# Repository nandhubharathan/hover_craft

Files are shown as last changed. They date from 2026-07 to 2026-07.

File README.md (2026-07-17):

# 🚁 Autonomous AI Hovercraft — v5.5

> **Self-correcting autonomous hovercraft** — if someone pushes it, tilts it, or the wind moves it off course, the craft detects the drift and steers itself back to its locked heading automatically. No input from the remote required.

**Platform:** Raspberry Pi Pico (RP2040) · MicroPython  
**Chassis:** 22 cm × 14.5 cm · ~400 g  
**Motors:** 2× Emax 1700KV BLDC · 9.2 cm 2-Blade Props  
**Servo:** MG90S (thrust vectoring / rudder)  
**Battery:** 11.1V 3S 80C LiPo  
**Modes:** Manual RC + Autonomous AI Stabilization

---

## 📁 Project Structure

```
hover_craft/
│
├── firmware/                        # All source code
│   ├── pico/                        # Raspberry Pi Pico (MicroPython)
│   │   ├── main.py                  # Dual-core entry point
│   │   ├── hover_control.py         # PWM, heading memory, safety
│   │   ├── mlp_logic.py             # TinyML inference engine (100 Hz)
│   │   └── weights.py               # MLP weights (int8 quantized)
│   │
│   ├── transmitter_nano/            # Arduino Nano — Hand Controller TX
│   │   └── transmitter_nano.ino     # 433 MHz TX, 6-byte packet
│   │
│   ├── receiver_nano/               # Arduino Nano — RX UART Bridge
│   │   └── receiver_nano.ino        # 433 MHz RX → Pico UART bridge
│   │
│   └── esp32_vision/                # ESP32-CAM — Vision + Ultrasonic
│       └── sketch_apr6a/
│           └── sketch_apr6a.ino     # Geometry + HC-SR04 streamer
│
├── 3d_designs/                      # 3D printable STL files (full chassis)
│   ├── 1-upper-hull-main-body.stl   # Main upper hull body
│   ├── 2-lower-hull.stl             # Lower hull base plate
│   ├── 3-thrust-motor-mount.stl     # Thrust BLDC motor bracket
│   ├── 4-roll-hoop.stl              # Roll protection hoop
│   ├── 5-lower-skirt-mount.stl      # Lower skirt attachment ring
│   ├── 6-upper-skirt-mount-complete.stl  # Upper skirt clamp assembly
│   ├── propeller.stl                # Prop guard / duct
│   ├── camerabox.stl                # ESP32-CAM enclosure
│   ├── joystick.stl                 # Handheld controller shell
│   └── joycover.stl                 # Controller top cover
│
├── simulation/                      # ROS2 / Gazebo SITL
│   ├── hovercraft.urdf              # Robot description
│   ├── hover_sim.launch.py          # ROS2 launch file
│   ├── sitl_bridge.py               # Software-in-the-loop bridge
│   └── world/
│       └── hover_lab.world          # Gazebo world
│
├── circuit_diagrams.md              # Full wiring diagrams (Mermaid)
├── Connection_Map.txt               # Pin-by-pin connection map
├── README.md                        # This file
└── .gitignore
```

---

## 🏗️ System Architecture

```
🎮 Hand Controller          📻 RF Link         🚁 Hovercraft
─────────────────           ──────────         ─────────────

TX Arduino Nano             433 MHz            RX Arduino Nano
  Joystick (A0/A1)   ─────►  ASK  ──────►     (UART Bridge)
  AI Switch  (D2)           2000bps              D12 ← RF DATA
  Lift Button (D3)                               D11 → Pico GP9
  D12 → RF TX DATA                           (1kΩ/2kΩ divider)
                                                      │
                                                      ▼
                                           Raspberry Pi Pico
                                           ┌──────────────────────────┐
                                           │ Core 0 (I/O)             │
                                           │  UART1 GP9 ← Nano Bridge │
                                           │  UART0 GP1 ← ESP32-Cam   │
                                           │  Shared State (mutex)    │
                                           │                          │
                                           │ Core 1 (Control 100Hz)   │
                                           │  MPU-6050 I2C (GP4/GP5)  │
                                           │  MLP TinyML Inference    │
                                           │  Heading Memory + PI     │
                                           │  hover_control PWM       │
                                           │       ↓      ↓      ↓   │
                                           │  GP16    GP17    GP18    │
                                           └───┼───────┼────────┼────┘
                                            Lift ESC Thrust  Rudder
                                            BLDC    ESC BLDC  Servo
```

### ESP32-CAM Sensor Node

```
ESP32-CAM ──── HC-SR04 Ultrasonic (GPIO 13 TRIG / GPIO 15 ECHO)
     │
     └── GPIO1 TX ──► Pico GP1 (UART0, 115200 bps)
         4-byte packet: [0xD4][aspect×10][bb_height][ultra_dist_cm]
```

---

## 🔌 Hardware Requirements

### On-Board (Hovercraft)

| Component | Qty | Notes |
|---|-----|---|
| Raspberry Pi Pico (RP2040) | 1 | Flight controller |
| Arduino Nano (ATmega328P) | 1 | RX UART Bridge |
| 433 MHz RX Module | 1 | ASK/OOK receiver |
| ESP32-CAM (AI-Thinker) | 1 | Vision + ultrasonic |
| HC-SR04 Ultrasonic | 1 | Proximity sensing |
| MPU-6050 IMU | 1 | Gyro + accelerometer |
| Emax 1700KV BLDC | 2 | Lift + Thrust motors |
| 30A ESC | 2 | Lift + Thrust ESCs |
| MG90S Servo | 1 | Rudder / thrust vector |
| 9.2 cm 2-Blade Prop | 2 | CW + CCW pair |
| 11.1V 3S 80C LiPo | 1 | Main power |
| 5V BEC | 1 | Regulated supply |
| 1kΩ / 2kΩ Resistors | 2 | 5V→3.3V level shifter |
| 4.7kΩ Resistors | 2 | I2C SDA/SCL pull-ups |
| ball bearing 6702 | 1 |15x21x4mm|

### Hand Controller (Transmitter)

| Component | Qty | Notes |
|---|-----|---|
| Arduino Nano (ATmega328P) | 1 | TX controller |
| 433 MHz TX Module | 1 | ASK/OOK transmitter |
| Dual-axis Joystick | 1 | Thrust + steer |
| Toggle Switch | 1 | AI mode enable |
| Momentary Push Button | 1 | Lift toggle |
| 9V Battery | 1 | Controller power |

---

## 📡 Wiring Summary

### RF Signal Chain

```
TX Nano D12 ──[433MHz RF]──► RX Nano D12
                                  │
                              RX Nano D11 (5V SoftwareSerial @ 57600bps)
                                  │
                            [1kΩ]─┬─── Pico GP9 (UART1 RX, 3.3V)
                                  │
                                [2kΩ]
                                  │
                                 GND
```

> ⚠️ **Critical:** The Nano outputs 5V on D11. The Pico GPIO is 3.3V max. The 1kΩ/2kΩ resistor divider is **mandatory** to avoid damaging the Pico.

### Pico Pin Map

| GPIO | Function | Protocol |
|---|---|---|
| GP0 | ESP32-Cam RX (Pico TX, reserved) | UART0 115200 |
| GP1 | ESP32-Cam TX → Pico RX | UART0 115200 |
| GP4 | MPU-6050 SDA | I2C0 400 kHz |
| GP5 | MPU-6050 SCL | I2C0 400 kHz |
| GP8 | Nano Bridge TX (reserved) | UART1 57600 |
| GP9 | Nano Bridge D11 → Pico RX | UART1 57600 |
| GP16 | Lift BLDC ESC | PWM 50 Hz |
| GP17 | Thrust BLDC ESC | PWM 50 Hz |
| GP18 | MG90S Rudder Servo | PWM 50 Hz |

### RX Nano (Bridge) Pin Map

| Pin | Function |
|-----|---|
| D12 | 433 MHz RX module DATA (RadioHead rxPin) |
| D11 | SoftwareSerial TX → Pico GP9 (via divider) |
| D10 | RadioHead PTT (unused, held HIGH) |
| 5V | Power from BEC |
| GND | Common ground with Pico |

---

## 📦 UART Packet Format

### RF Packet: TX Nano → RX Nano (6 bytes, RadioHead RH_ASK @ 2000bps)

| Byte | Field | Type | Range |
|---|---|---|---|
| 0 | thrust | uint8 | 0–255 |
| 1 | steer | int8 | -100…+100 |
| 2 | liftToggle | uint8 | 0 or 1 |
| 3 | aiMode | uint8 | 0 or 1 |
| 4 | brakeMode | uint8 | 0 or 1 |
| 5 | checksum | uint8 | XOR of bytes 0–4 |

### UART Frame: RX Nano → Pico GP9 (8 bytes, 57600 bps 8N1)

```
[0xAA][0x55][thrust][steer][lift][ai][brake][checksum]
 sync0  sync1   1B     1B    1B   1B    1B      1B
```

Pico unpack: `struct.unpack('<BbBBBB', frame[2:])` 

---

## 🧠 MLP Neural Network

**Architecture:** 7 inputs → 8 hidden (tanh) → 4 outputs (sigmoid)

| Layer | Nodes | Activation |
|---|---|---|
| Input | 7 | — |
| Hidden | 8 | tanh (256-entry LUT) |
| Output | 4 | sigmoid (via tanh identity) |

**Inputs:** `[ax, ay, az, joy_x, joy_y, obstacle_flag, yaw_rate]`  
**Outputs:** `[lift_trim_µs, thrust_trim_µs, servo_trim_µs, alert/confidence]`

**TinyML Optimizations:**
- `int8` quantized weights (range -127..127), dequantized × (1/127)
- 256-entry LUT tanh/sigmoid — ~8× faster than `math.tanh` on M0+
- Pre-allocated buffers — zero GC pressure at 100 Hz
- Confidence gate: if `alert < 0.3` → all trims zeroed

**Target:** < 10 ms per inference on RP2040 @ 125 MHz

---

## ⚙️ PWM Reference (1700KV @ 12.6V)

| PWM | RPM | Purpose |
|-----|-----|---|
| 1000 µs | 0 | ESC armed / motor off |
| 1100 µs | ~2,142 | Thrust idle / dip manoeuvre |
| 1350 µs | ~7,497 | **Lift hover target** |
| 1500 µs | ~10,710 | Servo neutral |
| 1900 µs | ~19,278 | Thrust maximum |

---

## 🚀 Quick Start

### 1. Flash the Pico

```bash
cd firmware/pico
mpremote cp main.py hover_control.py mlp_logic.py weights.py :
```

### 2. Flash TX Arduino Nano

Open `firmware/transmitter_nano/transmitter_nano.ino` in Arduino IDE → select **Arduino Nano** → Upload.

### 3. Flash RX Arduino Nano (Bridge)

Open `firmware/receiver_nano/receiver_nano.ino` in Arduino IDE → select **Arduino Nano** → Upload.  
Verify Serial Monitor shows: `[OK] RadioHead ready on D12`

### 4. Flash ESP32-CAM

Open `firmware/esp32_vision/sketch_apr6a/sketch_apr6a.ino` in Arduino IDE → select **AI Thinker ESP32-CAM** → Upload.

### 5. Bench Test (NO PROPELLERS)

Pico Serial (Thonny) should show:
```
[CORE 0] I/O thread live — CAM UART0 | Nano UART1 @ 57600 baud
[CORE 1] ESCs armed — 100 Hz
[TX→PICO] THR=0 STR=0 LIFT=0 AI=0 BRK=0
```

### 6. Verify PWM Signals

| Channel | Idle | Active |
|---|---|---|
| GP16 (Lift) | 1000 µs | 1350 µs |
| GP17 (Thrust) | 1000 µs | scales with joystick |
| GP18 (Servo) | 1500 µs | ±500 µs with steer |

---

## 🛡️ Safety Checklist

- [ ] Replace placeholder `weights.py` with trained MLP weights before flight
- [ ] Confirm 6-byte TX packet matches `<BbBBBB>` Pico struct format
- [ ] Bench test without propellers — verify all PWM signals
- [ ] Test thrust-dip: observe 100 ms power dip during 180° servo flip
- [ ] Test failsafe: disconnect TX, confirm e-stop within 500 ms
- [ ] Verify voltage divider on Nano D11 → Pico GP9 before powering
- [ ] Add hardware kill switch between LiPo and ESCs
- [ ] Confirm all GNDs are tied: Nano RX ↔ Pico ↔ ESCs ↔ BEC

---

## 🔬 AI Autonomous Mode

When **AI Mode** is toggled ON (D2 switch on transmitter), the craft becomes self-correcting:

### 🔄 Self-Correction — The Key Feature

> **If the craft is pushed, bumped, tilted, or drifts off course by wind or surface irregularity — it corrects itself back to its original heading without any input from the remote.**

This works through a two-layer system running at 100Hz:

- **Heading Memory (Angle Integration):** The gyroscope's yaw rate is continuously integrated into a heading error value (in degrees). If the craft rotates away from its locked heading — whether from a bump, wind, or uneven surface — the error accumulates. Once it crosses 20°, the rudder servo fires a fixed 250 µs correction force to push it back.
- **Zero-Crossing Disengage:** When the craft returns to its locked heading, the correction immediately disengages and a 300 ms cooldown prevents the return momentum from triggering an over-correction in the opposite direction.
- **Tilt Correction (MLP):** The TinyML neural network reads the accelerometer and fires servo trim corrections (up to ±312 µs) to counteract roll tilt in real time.
- **Pilot Overrule:** If you move the joystick, heading memory clears instantly. On release, the craft re-locks to its new position as the fresh zero.

### Full Feature List

1. **Autonomous Heading Hold** — Locks heading at AI-on moment; corrects any external disturbance back to it
2. **Tilt-Rudder Correction** — MLP roll compensation via servo trim at 100 Hz
3. **Human Detection** — ESP32-CAM bounding box geometry → `STATE_BRAKING` (latched, joystick reset to exit)
4. **Ultrasonic Proximity Stop** — Fused with camera: forward thrust blocked within 22 cm, steering preserved for evasion
5. **Torque Offset Compensation** — Proportional rudder bias cancels lift motor rotational torque
6. **Gyro Debounce (Sustained-Spin Gate)** — 5 consecutive ticks above deadband required before integrating — filters vibration spikes
7. **AI Packet Debounce** — 5 consecutive `ai_mode=True` RF packets required before AI activates — prevents corrupt-packet false triggers
8. **Pilot Overrule + Heading Re-lock** — Pilot steering clears heading memory; heading re-locks on stick release

---

---

## 🖨️ 3D Design Files

All structural parts are fully 3D printable. Files are in the `3d_designs/` folder (STL format, ready to slice).

| File | Part | Notes |
|---|---|---|
| `1-upper-hull-main-body.stl` | Upper hull | Main body — houses Pico, Nano, IMU |
| `2-lower-hull.stl` | Lower hull | Base plate — mounts ESCs and LiPo |
| `3-thrust-motor-mount.stl` | Thrust motor bracket | Rear BLDC mount with servo clearance |
| `4-roll-hoop.stl` | Roll hoop | Protects electronics on tip-over |
| `5-lower-skirt-mount.stl` | Lower skirt ring | Clamps garbage-bag skirt to hull base |
| `6-upper-skirt-mount-complete.stl` | Upper skirt clamp | Seals skirt top to hull |
| `propeller.stl` | Prop guard / duct | Optional duct for efficiency |
| `camerabox.stl` | ESP32-CAM enclosure | Front-facing camera housing |
| `joystick.stl` | Controller shell | Handheld TX enclosure body |
| `joycover.stl` | Controller cover | TX enclosure top cap |

**Recommended print settings:** PLA/PETG · 20% infill · 0.2 mm layer height · 3 perimeters

---

## 🌐 Simulation (ROS2 / Gazebo)

```bash
# Launch Gazebo simulation
ros2 launch simulation/hover_sim.launch.py

# Run SITL bridge (connects Pico serial to ROS2)
python3 simulation/sitl_bridge.py
```

---

## 📋 Libraries Required

### Arduino (Nano TX + RX)
- [RadioHead](http://www.airspayce.com/mikem/arduino/RadioHead/) — `RH_ASK` driver
- `SPI.h` — bundled with Arduino IDE
- `SoftwareSerial.h` — bundled with Arduino IDE (RX Nano only)

### ESP32-CAM
- `esp_camera.h` — bundled with ESP32 Arduino core

### Pico (MicroPython)
- `machine`, `_thread`, `struct`, `time` — all built-in to MicroPython

---

## ⚠️ Known Notes

- **Baud rate:** `receiver_nano.ino` SoftwareSerial runs at **57600 bps**. Ensure `main.py` `UART(1, baudrate=57600)` matches.
- **SD card conflict:** ESP32-CAM GPIO 13/15 are shared with the SD card slot. Do **not** initialize the SD card.
- **Prop direction:** Lift prop pushes air DOWN (into skirt). Thrust prop pushes air AFT through rudder channel.
- **Weights:** `weights.py` ships with Xavier-initialized placeholder values. **Replace with trained weights before any flight.**
- **3.3V rule:** MPU-6050 must be powered from Pico 3V3 pin only.

---

*Karunya Institute of Technology and Sciences — B.Tech Project*

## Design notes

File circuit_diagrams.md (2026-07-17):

# Hovercraft v5.5 — Circuit Diagrams

## 1. Hovercraft (On-Board Electronics)

### System Overview

```mermaid
graph TB
    subgraph POWER["🔋 Power"]
        BATT["LiPo Battery<br/>11.1V 3S"]
        BEC["BEC 5V"]
    end

    subgraph BRAIN["🧠 Flight Controller"]
        PICO["Raspberry Pi Pico<br/>(RP2040)"]
    end

    subgraph SENSORS["📡 Sensors"]
        IMU["MPU-6050<br/>Gyro + Accel"]
        ESP["ESP32-CAM<br/>AI-Thinker"]
        ULTRA["HC-SR04<br/>Ultrasonic"]
    end

    subgraph ACTUATORS["⚙️ Actuators"]
        LIFT_ESC["Lift ESC"]
        LIFT_MOTOR["Lift BLDC<br/>1700KV"]
        THRUST_ESC["Thrust ESC"]
        THRUST_MOTOR["Thrust BLDC<br/>1700KV"]
        SERVO["Rudder Servo<br/>MG90S"]
    end

    subgraph RF["📻 RF Receive Chain"]
        RX433["433 MHz RX<br/>Module"]
        NANO_RX["Arduino Nano<br/>(RX UART Bridge)"]
    end

    BATT --> BEC
    BATT --> LIFT_ESC
    BATT --> THRUST_ESC
    BEC --> PICO
    BEC --> ESP
    BEC --> SERVO
    BEC --> NANO_RX

    PICO -->|"GP16 PWM 50Hz"| LIFT_ESC --> LIFT_MOTOR
    PICO -->|"GP17 PWM 50Hz"| THRUST_ESC --> THRUST_MOTOR
    PICO -->|"GP18 PWM 50Hz"| SERVO

    IMU -->|"I2C (GP4/GP5) 400kHz"| PICO
    PICO -->|"3V3"| IMU
    ESP -->|"UART0 GP1 115200bps"| PICO
    ULTRA -->|"TRIG GPIO13"| ESP
    ESP -->|"ECHO GPIO15 (via divider)"| ULTRA

    RX433 -->|"DATA → D12"| NANO_RX
    NANO_RX -->|"D11 → 1kΩ/2kΩ → GP9<br/>SoftSerial 57600bps"| PICO
    BEC -->|"5V"| RX433
```

---

### Complete Signal Chain (RF → Control)

```mermaid
graph LR
    subgraph TX["🎮 Transmitter (Hand Controller)"]
        JOY["Joystick<br/>A0/A1"]
        SW["Switches<br/>D2 D3"]
        TX_NANO["TX Nano<br/>(ATmega328P)"]
        RF_TX["433MHz TX<br/>ASK Module"]
    end

    subgraph AIR["🌊 RF Link"]
        LINK["433 MHz OOK<br/>2000 bps"]
    end

    subgraph CRAFT["🚁 Hovercraft"]
        RF_RX["433MHz RX<br/>Module"]
        RX_NANO["RX Nano<br/>(UART Bridge)"]
        DIV["1kΩ/2kΩ<br/>Divider"]
        PICO2["Pico GP9<br/>UART1 RX"]
    end

    JOY --> TX_NANO
    SW --> TX_NANO
    TX_NANO -->|"D12 RadioHead"| RF_TX
    RF_TX --> LINK --> RF_RX
    RF_RX -->|"DATA → D12"| RX_NANO
    RX_NANO -->|"D11 SoftSerial<br/>57600bps"| DIV
    DIV -->|"3.3V safe"| PICO2
```

---

### Pico (RP2040) Pin Map

```mermaid
graph LR
    subgraph PICO["Raspberry Pi Pico (RP2040)"]
        direction TB
        GP0["GP0 — UART0 TX (reserved)"]
        GP1["GP1 — UART0 RX ← ESP32-Cam"]
        GP4["GP4 — I2C0 SDA"]
        GP5["GP5 — I2C0 SCL"]
        GP8["GP8 — UART1 TX (reserved)"]
        GP9["GP9 — UART1 RX ← Nano RX Bridge"]
        GP16["GP16 — Lift ESC PWM"]
        GP17["GP17 — Thrust ESC PWM"]
        GP18["GP18 — Servo PWM"]
        V3["3V3 OUT → MPU-6050"]
        GND["GND — Common"]
    end

    ESP32["ESP32-CAM GPIO1 TX"] -->|"115200 baud"| GP1
    MPU_SDA["MPU-6050 SDA"] <-->|"I2C 400kHz"| GP4
    MPU_SCL["MPU-6050 SCL"] <-->|"I2C 400kHz"| GP5
    NANO_D11["Nano RX D11<br/>(via 1kΩ/2kΩ divider)"] -->|"57600 baud"| GP9
    GP16 -->|"50 Hz PWM"| LIFT["Lift ESC Signal"]
    GP17 -->|"50 Hz PWM"| THRUST["Thrust ESC Signal"]
    GP18 -->|"50 Hz PWM"| RUDDER["Rudder Servo Signal"]
```

---

### Arduino Nano RX Bridge — Pin Map

```mermaid
graph LR
    subgraph NANO_RX_BOARD["Arduino Nano (RX UART Bridge)"]
        direction TB
        ND12["D12 — RadioHead RX Data"]
        ND11["D11 — SoftwareSerial TX (to Pico)"]
        ND10["D10 — RadioHead PTT (unused, HIGH)"]
        N5V["5V — VCC from BEC"]
        NGND["GND — Common"]
    end

    RF433["433 MHz RX<br/>Module DATA"] -->|"OOK signal"| ND12
    ND11 -->|"5V 57600bps"| R1["1kΩ"]
    R1 --> PICO_GP9["Pico GP9 (UART1 RX)"]
    R1 --> R2["2kΩ"]
    R2 --> GND_NODE["GND"]
    N5V --- BEC_5V["BEC 5V"]
    NGND --- PICO_GND["Pico GND"]
```

---

### Detailed Wiring Table — Hovercraft

| Connection | From | Pin | To | Pin | Notes |
|---|---|-----|-----|-----|---|
| **Lift ESC** | Pico | GP16 | ESC Signal | White | 50 Hz PWM, 1000–1350 µs |
| **Thrust ESC** | Pico | GP17 | ESC Signal | White | 50 Hz PWM, 1000–1900 µs |
| **Rudder Servo** | Pico | GP18 | Servo Signal | Orange | 50 Hz PWM, 500–2500 µs |
| **IMU SDA** | Pico | GP4 | MPU-6050 | SDA | I2C0 @ 400 kHz, 3.3V |
| **IMU SCL** | Pico | GP5 | MPU-6050 | SCL | I2C0 @ 400 kHz, 3.3V |
| **IMU Power** | Pico | 3V3 | MPU-6050 | VCC | 3.3V only |
| **IMU Ground** | Pico | GND | MPU-6050 | GND | Common ground |
| **ESP32 → Pico** | ESP32 | GPIO1 (TX) | Pico | GP1 (RX) | UART0, 115200 baud |
| **Ultrasonic TRIG** | ESP32 | GPIO13 | HC-SR04 | TRIG | 3.3V output |
| **Ultrasonic ECHO** | ESP32 | GPIO15 | HC-SR04 | ECHO | ⚠️ 5V→3.3V divider needed |
| **433MHz RX → Nano** | 433MHz RX | DATA | Nano RX | D12 | RadioHead RH_ASK rxPin |
| **Nano RX → Divider** | Nano RX | D11 | Resistor | 1kΩ | SoftSerial TX 5V |
| **Divider → Pico** | Resistor | 2kΩ | Pico | GP9 (RX) | UART1, 57600 baud, 3.3V |
| **Nano RX Power** | BEC | 5V | Nano RX | VIN/5V | 5V supply |
| **Nano RX Ground** | Nano RX | GND | Pico | GND | MUST share common ground |

### Nano RX → Pico Voltage Divider (5V → 3.3V)

```
Nano RX D11 (5V) ──[1kΩ]──┬── Pico GP9 (UART1 RX, 3.3V)
                            │
                          [2kΩ]
                            │
                           GND
```

> [!IMPORTANT]
> The Arduino Nano outputs **5V** logic on D11. The Pico GPIO is **3.3V only** — connecting them directly **will damage the Pico**. The 1kΩ/2kΩ resistor divider brings 5V down to ~3.33V (safe). The SoftwareSerial runs at **57600 bps**; the Pico UART1 must also be configured at 57600 bps.

---

### ESP32-CAM Wiring

```mermaid
graph LR
    subgraph ESP["ESP32-CAM (AI-Thinker)"]
        GPIO1["GPIO 1 — Serial TX"]
        GPIO3["GPIO 3 — Serial RX (unused)"]
        GPIO13["GPIO 13 — HC-SR04 TRIG"]
        GPIO15["GPIO 15 — HC-SR04 ECHO"]
        ESP_5V["5V IN"]
        ESP_GND["GND"]
    end

    GPIO1 -->|"115200 baud"| PICO_RX["Pico GP1 (UART0 RX)"]
    GPIO13 -->|"10µs pulse"| TRIG["HC-SR04 TRIG"]
    ECHO_PIN["HC-SR04 ECHO"] -->|"via 5V→3.3V divider"| GPIO15
    ESP_5V --- BEC_5V["BEC 5V"]
    ESP_GND --- COMMON_GND["Common GND"]
```

> [!WARNING]
> GPIO 13 and 15 are shared with the SD card slot on the AI-Thinker ESP32-CAM. **Do NOT initialize the SD card** when using the ultrasonic sensor.

---

## 2. Remote Transmitter (Handheld Controller)

### Transmitter Overview

```mermaid
graph TB
    subgraph REMOTE["🎮 Remote Controller"]
        direction TB
        TX_NANO2["Arduino Nano<br/>(ATmega328P)"]
        JOY2["Dual-Axis<br/>Joystick"]
        AI_SW["AI Mode<br/>Toggle Switch"]
        LIFT_SW["Lift<br/>Push Button"]
        TX_MOD["433 MHz TX<br/>ASK Module"]
        BATT_TX["9V Battery"]
    end

    BATT_TX -->|"VIN"| TX_NANO2
    JOY2 -->|"A0 (Thrust)<br/>A1 (Steer)"| TX_NANO2
    AI_SW -->|"D2"| TX_NANO2
    LIFT_SW -->|"D3"| TX_NANO2
    TX_NANO2 -->|"D12 (Data)"| TX_MOD
    TX_NANO2 -->|"D10 (PTT)"| TX_MOD
```

---

### Transmitter Pin Map

```mermaid
graph LR
    subgraph NANO_TX["Arduino Nano (TX Controller)"]
        direction TB
        A0_TX["A0 — Thrust (Joystick X)"]
        A1_TX["A1 — Steer (Joystick Y)"]
        D2_TX["D2 — AI Mode Switch (PULLUP)"]
        D3_TX["D3 — Lift Button (PULLUP)"]
        D10_TX["D10 — PTT (RadioHead)"]
        D11_TX["D11 — RX (unused)"]
        D12_TX["D12 — TX Data (RadioHead)"]
        VIN_TX["VIN — 9V Battery"]
        V5_TX["5V OUT — TX Module VCC"]
        GND_TX["GND"]
    end

    JOY_X["Joystick X<br/>(Thrust/Brake)"] --> A0_TX
    JOY_Y["Joystick Y<br/>(Steer L/R)"] --> A1_TX
    AI_TOG["AI Toggle<br/>Switch"] --> D2_TX
    LIFT_BTN["Lift Button<br/>(Momentary)"] --> D3_TX
    D12_TX --> RF_TX2["433 MHz TX<br/>Data Pin"]
    D10_TX --> RF_PTT["433 MHz TX<br/>PTT Pin"]
    V5_TX --> RF_VCC["433 MHz TX<br/>VCC"]
```

---

### Detailed Wiring Table — Transmitter

| Connection | From | Pin | To | Pin | Notes |
|---|---|-----|-----|-----|---|
| **Joystick X** | Joystick | VRx | TX Nano | A0 | Thrust axis (fwd/back) |
| **Joystick Y** | Joystick | VRy | TX Nano | A1 | Steer axis (left/right) |
| **Joystick VCC** | TX Nano | 5V | Joystick | +5V | 5V reference |
| **Joystick GND** | TX Nano | GND | Joystick | GND | Common ground |
| **AI Toggle** | Switch | COM | TX Nano | D2 | `INPUT_PULLUP` — LOW = AI ON |
| **AI Toggle GND** | Switch | NC | TX Nano | GND | Switch to ground |
| **Lift Button** | Button | COM | TX Nano | D3 | `INPUT_PULLUP` — press to toggle |
| **Lift Button GND** | Button | NC | TX Nano | GND | Switch to ground |
| **433 TX Data** | TX Nano | D12 | TX Module | DATA | RadioHead RH_ASK @ 2000 bps |
| **433 TX PTT** | TX Nano | D10 | TX Module | PTT | Push-to-talk (RadioHead) |
| **433 TX VCC** | TX Nano | 5V | TX Module | VCC | 5V supply |
| **433 TX GND** | TX Nano | GND | TX Module | GND | Common ground |
| **433 TX Antenna** | — | — | TX Module | ANT | 17.3 cm wire (¼λ @ 433 MHz) |

---

### Joystick Axis Mapping

```
                   FORWARD (thrust > 0)
                        ↑
                   ┌────┼────┐
                   │    │    │
         LEFT ─────┼────●────┼───── RIGHT
        (steer-)   │    │    │   (steer+)
                   └────┼────┘
                        ↓
                   BACKWARD (BRK = 1)
```

| Joystick Position | Nano Value | Pico Variable | Effect |
|---|---|---|---|
| Forward | `rawX > 552` | `joy_y = 0.0–1.0` | Forward thrust |
| Backward | `rawX < 472` | `brake_mode = True` | Turn-around mode |
| Left | `rawY < 472` | `joy_x < 0` | Steer left |
| Right | `rawY > 552` | `joy_x > 0` | Steer right |
| Center | `472–552` | `joy_x/y ≈ 0` | Neutral (deadzone) |

---

### Serial Packet Format (TX Nano → 433MHz → RX Nano → Pico)

```
RF Packet (6 bytes, RadioHead RH_ASK):
┌────────┬───────┬──────┬───────┬──────────┬──────────┐
│ thrust │ steer │ lift │  AI   │  brake   │ checksum │
│ 0–255  │ ±100  │ 0/1  │  0/1  │   0/1    │   XOR    │
└────────┴───────┴──────┴───────┴──────────┴──────────┘
  1 B      1 B    1 B    1 B      1 B         1 B

UART Frame (8 bytes, RX Nano → Pico at 57600 bps):
┌──────┬──────┬────────┬───────┬──────┬───────┬──────────┬──────────┐
│ 0xAA │ 0x55 │ thrust │ steer │ lift │  AI   │  brake   │ checksum │
│ sync │ sync │ 0–255  │ ±100  │ 0/1  │  0/1  │   0/1    │   XOR    │
└──────┴──────┴────────┴───────┴──────┴───────┴──────────┴──────────┘
  1 B    1 B    1 B      1 B    1 B    1 B      1 B         1 B

Pico UART1: baudrate=57600, GP9 RX, 8N1
Pico struct.unpack: '<BbBBBB' (6 bytes after stripping 2 sync bytes)
```

---

## 3. Power Distribution

```mermaid
graph TD
    LIPO["LiPo 3S 11.1V"] --> LIFT_ESC2["Lift ESC<br/>(direct)"]
    LIPO --> THRUST_ESC2["Thrust ESC<br/>(direct)"]
    LIPO --> BEC2["BEC<br/>11.1V → 5V"]
    BEC2 --> PICO_5V["Pico VSYS (5V)"]
    BEC2 --> SERVO_V["Servo VCC (5V)"]
    BEC2 --> ESP_V["ESP32-CAM VCC (5V)"]
    BEC2 --> NANO_RX_V["Nano RX Bridge VIN (5V)"]
    BEC2 --> ULTRA_V["HC-SR04 VCC (5V)"]
    PICO_5V --> PICO_3V["Pico 3V3 OUT"]
    PICO_3V --> IMU_V["MPU-6050 VCC (3.3V)"]

    TX_BATT["9V Battery (TX)"] --> TX_NANO_V["TX Nano VIN"]
    TX_NANO_V --> TX_5V["TX Nano 5V"]
    TX_5V --> RF_TX_V["433MHz TX Module VCC"]
```

> [!TIP]
> Use a dedicated BEC (not the ESC's built-in BEC) for clean 5V. ESC BECs have switching noise that affects the MPU-6050 gyro readings.

---

## 4. MLP Neural Network Architecture

```
Input Layer (7 nodes)          Hidden Layer (8 nodes)      Output Layer (4 nodes)
─────────────────────          ──────────────────────      ─────────────────────
 ax  (accel X, g)    ──┐
 ay  (accel Y, g)    ──┤       ┌──────────────────┐        lift_trim_us  (±50 µs)
 az  (accel Z, g)    ──┼──────►│  8 × tanh nodes  ├───────►thrust_trim_us(±50 µs)
 joy_x (steer ±1)   ──┤       │  (LUT approx)    │        servo_trim_us (±312 µs)
 joy_y (thrust ±1)  ──┤       └──────────────────┘        alert / conf  (0–1)
 obstacle (0/1)      ──┤
 yaw_rate (°/s /250) ──┘

Weights: int8 quantized (-127..127), dequantized × (1/127)
Activations: 256-entry LUT tanh / sigmoid (no math.exp)
Inference: < 10 ms on RP2040 @ 125 MHz (100 Hz budget)
```

---

## 5. On-Board Dual-Core Architecture

```
┌──────────────────────────────────────────────────────────┐
│                    Raspberry Pi Pico (RP2040)            │
│                                                          │
│  ┌─ Core 0 (I/O) ─────────────────┐                     │
│  │  UART0 (GP1) ← ESP32-Cam       │                     │
│  │   Obstacle veto + Geometry 0xD4│                     │
│  │  UART1 (GP9) ← Nano RX Bridge  │                     │
│  │   57600bps framed packet parser │                     │
│  │            ↓                   │                     │
│  │   Shared State (thread-safe)   │                     │
│  │   joy_x/y, lift, ai, brake,    │                     │
│  │   obstacle_dir, cam_aspect,    │                     │
│  │   cam_height, ultra_dist       │                     │
│  └────────────────────────────────┘                     │
│                     ↓ _lock (mutex)                      │
│  ┌─ Core 1 (Control 100Hz) ───────────────────────┐     │
│  │  MPU-6050 I2C (GP4/GP5)                        │     │
│  │  MLP Inference (mlp_logic.py / weights.py)     │     │
│  │  hover_control.compute_targets()               │     │
│  │  Heading Memory + Pilot Overrule               │     │
│  │  Human Detection + Obstacle Veto               │     │
│  │            ↓                                   │     │
│  │   GP16 Lift ESC    GP17 Thrust ESC   GP18 Servo│     │
│  └────────────────────────────────────────────────┘     │
└──────────────────────────────────────────────────────────┘
```

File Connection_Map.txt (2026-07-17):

═══════════════════════════════════════════════════════════════
  HOVERCRAFT WIRING — CONNECTION MAP  (v5.5 — Nano RX Bridge)
  TX Nano ──433MHz──► RX Nano ──UART──► Raspberry Pi Pico
═══════════════════════════════════════════════════════════════

┌─────────────────────────────────────────────────────────────┐
│               TRANSMITTER (Arduino Nano — TX)               │
├──────────┬────────────┬─────────────────────────────────────┤
│ Pin      │ Type       │ Connection                          │
├──────────┼────────────┼─────────────────────────────────────┤
│ A0       │ Analog In  │ Joystick X-axis (Thrust)            │
│ A1       │ Analog In  │ Joystick Y-axis (Steering)          │
│ D2       │ Digital In │ AI Mode Toggle Switch (INPUT_PULLUP)│
│ D3       │ Digital In │ Lift Toggle Push Button (PULLUP)    │
│ D10      │ Digital Out│ 433 MHz TX PTT Pin (RadioHead)      │
│ D12      │ Digital Out│ 433 MHz TX Data Pin (RadioHead)     │
│ 5V       │ Power      │ Joystick VCC + TX Module VCC        │
│ GND      │ Power      │ Common Ground                       │
└──────────┴────────────┴─────────────────────────────────────┘

       ┌──────────433 MHz RF Link──────────┐
       │   TX Nano D12  ───►  RX Nano D12  │
       │   ASK @ 2000 bps (RadioHead)      │
       └───────────────────────────────────┘

┌─────────────────────────────────────────────────────────────┐
│           RECEIVER BRIDGE (Arduino Nano — RX)               │
│   Role: 433 MHz Wireless → Wired UART Bridge to Pico        │
├──────────┬────────────┬─────────────────────────────────────┤
│ Pin      │ Type       │ Connection                          │
├──────────┼────────────┼─────────────────────────────────────┤
│ D12      │ Digital In │ ← 433 MHz RX Module DATA pin        │
│ D10      │ Digital Out│ → 433 MHz RX PTT (unused, disabled) │
│ D11      │ SoftSerial │ → 1kΩ → Pico GP9  (UART1 RX)       │
│          │   TX       │   (+ 2kΩ to GND voltage divider)   │
│ 5V       │ Power      │ From BEC (or USB for bench testing) │
│ GND      │ Power      │ → Pico GND (common ground)         │
└──────────┴────────────┴─────────────────────────────────────┘

  Nano RX D11 ──[1kΩ]──┬── Pico GP9 (UART1 RX, 3.3V)
  (5V logic)            │
                       [2kΩ]
                        │
                       GND
  ⚠  MANDATORY: 5V Nano TX → 3.3V Pico RX level-shift!

  UART Protocol (Nano → Pico, 57600 bps, 8N1):
  [0xAA][0x55][thrust][steer][lift][ai][brake][checksum]
   sync0  sync1   1B     1B   1B   1B    1B      XOR

┌─────────────────────────────────────────────────────────────┐
│                 FLIGHT CONTROLLER (Raspberry Pi Pico)       │
├──────────┬────────────┬─────────────────────────────────────┤
│ Pin      │ Type       │ Connection                          │
├──────────┼────────────┼─────────────────────────────────────┤
│ GP0      │ UART0 TX   │ → ESP32-Cam GPIO3 RX (reserved)    │
│ GP1      │ UART0 RX   │ ← ESP32-Cam GPIO1 TX (115200 bps)  │
│ GP4      │ I2C0 SDA   │ ↔ MPU-6050 SDA (+ 4.7kΩ pull-up)  │
│ GP5      │ I2C0 SCL   │ ↔ MPU-6050 SCL (+ 4.7kΩ pull-up)  │
│ GP8      │ UART1 TX   │ → (reserved / unused)              │
│ GP9      │ UART1 RX   │ ← Nano RX D11 (via 1kΩ/2kΩ divider│
│          │            │   57600 bps SoftwareSerial)        │
│ GP16     │ PWM        │ → Lift BLDC ESC Signal              │
│ GP17     │ PWM        │ → Thrust BLDC ESC Signal            │
│ GP18     │ PWM        │ → MG90S Rudder Servo Signal         │
│ 3V3      │ Power      │ MPU-6050 VCC (3.3V ONLY!)           │
│ VSYS     │ Power      │ From BEC 5V (via LiPo regulator)    │
│ GND      │ Power      │ Common Ground                       │
└──────────┴────────────┴─────────────────────────────────────┘

═══════════════════════════════════════════════════════════════
  PACKET FORMAT (8 bytes total, Nano→Pico UART frame)
═══════════════════════════════════════════════════════════════

  Byte  Field       Type      Range     Notes
  ────  ─────────   ────────  ────────  ──────────────────────
  [0]   sync0       uint8     0xAA      Frame start marker
  [1]   sync1       uint8     0x55      Frame start marker
  [2]   thrust      uint8     0–255     Mapped to ESC 1000–2000µs
  [3]   steer       int8→u8   ±100      Pico re-interprets as int8
  [4]   liftToggle  uint8     0 or 1    Lift motor on/off state
  [5]   aiMode      uint8     0 or 1    Autonomous AI enable
  [6]   brakeMode   uint8     0 or 1    Joystick pulled back
  [7]   checksum    uint8     XOR       thrust^steer^lift^ai^brake

  Pico struct.unpack format: '<BbBBBB' (6 payload bytes after sync)

═══════════════════════════════════════════════════════════════
  SIGNAL CHAIN
═══════════════════════════════════════════════════════════════

  Joystick/Buttons
       │
       ▼
  TX Nano (ATmega328P)
  ├── Reads analog joystick (A0/A1), digital switches (D2/D3)
  ├── Builds 6-byte HoverPacket struct with XOR checksum
  └── Transmits via RadioHead RH_ASK @ 2000 bps on D12
       │
       ▼  [433 MHz OOK/ASK RF — one-way link]
       │
  RX Nano (ATmega328P)  ← NEW BRIDGE BOARD
  ├── RadioHead RH_ASK receives on D12
  ├── Validates checksum
  ├── Wraps in 8-byte framed packet [0xAA][0x55][...][csum]
  └── Forwards via SoftwareSerial on D11 @ 57600 bps
       │
       ▼  [Wired UART — 5V→3.3V voltage divider]
       │
  Raspberry Pi Pico (RP2040) — GP9 UART1 RX
  ├── Parses framed packet, validates sync + checksum
  ├── Core 0: I/O — feeds shared state (joy_x, joy_y, lift, ai, brake)
  └── Core 1: 100 Hz control loop → MLP → PWM → ESCs + Servo

═══════════════════════════════════════════════════════════════
  ESP32-CAM (AI-Thinker) — Obstacle + Geometry Sensor
═══════════════════════════════════════════════════════════════

  GPIO 1  → Pico GP1 (UART0 RX) @ 115200 bps
  GPIO 13 → HC-SR04 TRIG
  GPIO 15 ← HC-SR04 ECHO (via 5V→3.3V divider)
  5V IN   ← BEC 5V
  GND     → Common GND

  Packet: [0xD4][aspect_x10][bb_height][ultra_dist_cm]  4 bytes

═══════════════════════════════════════════════════════════════
  POWER WIRING
═══════════════════════════════════════════════════════════════

  3S LiPo (11.1 V)
    ├── ESC 1 (Lift BLDC)    → BEC 5V out
    ├── ESC 2 (Thrust BLDC)
    └── BEC 5V
          ├── Pico VSYS
          ├── Servo VCC
          ├── ESP32-Cam VCC
          ├── HC-SR04 VCC
          └── Nano RX VIN (or USB for bench)

  Pico 3V3 OUT → MPU-6050 VCC
  TX Nano      → Separate 9V battery or USB (hand controller)
  433 MHz TX   → TX Nano 5V pin
  433 MHz RX   → Nano RX 5V pin

═══════════════════════════════════════════════════════════════
  SAFETY NOTES
═══════════════════════════════════════════════════════════════

  ⚠  Nano RX D11 is 5V — MUST use 1kΩ/2kΩ divider to Pico GP9
  ⚠  433 MHz RX module VCC → Nano 5V (NOT Pico 3V3)
  ⚠  All GNDs connected: Nano RX GND ↔ Pico GND ↔ ESC GND
  ⚠  Remove propellers for ALL bench testing
  ⚠  Add hardware kill switch between LiPo and ESCs
  ⚠  MPU-6050 I2C needs 4.7kΩ pull-up resistors on SDA/SCL
  ⚠  Do NOT initialise SD card on ESP32-CAM (shares GPIO 13/15)

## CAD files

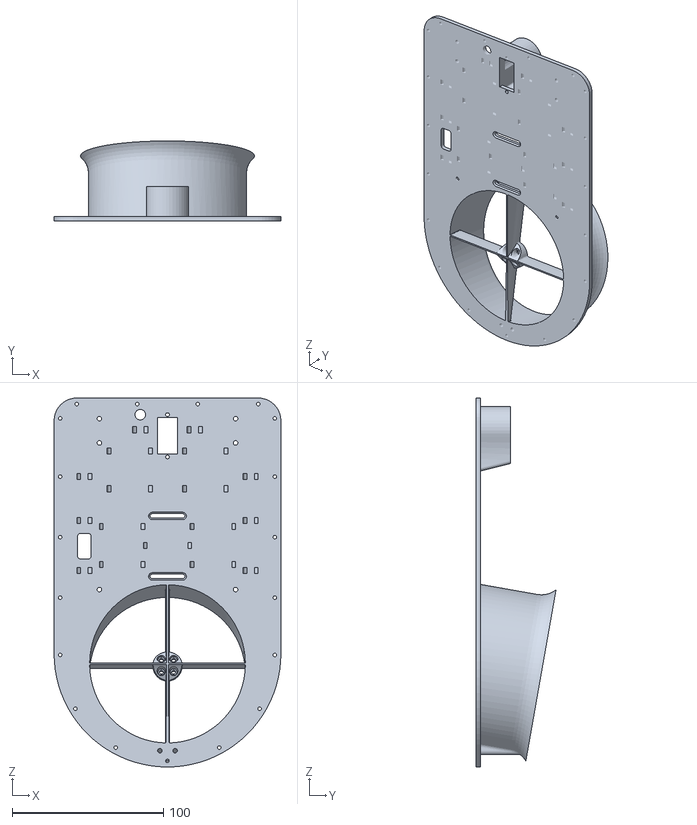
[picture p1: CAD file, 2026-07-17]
3d_designs/1-upper-hull-main-body.stl
150.0 x 53.0 x 244.0

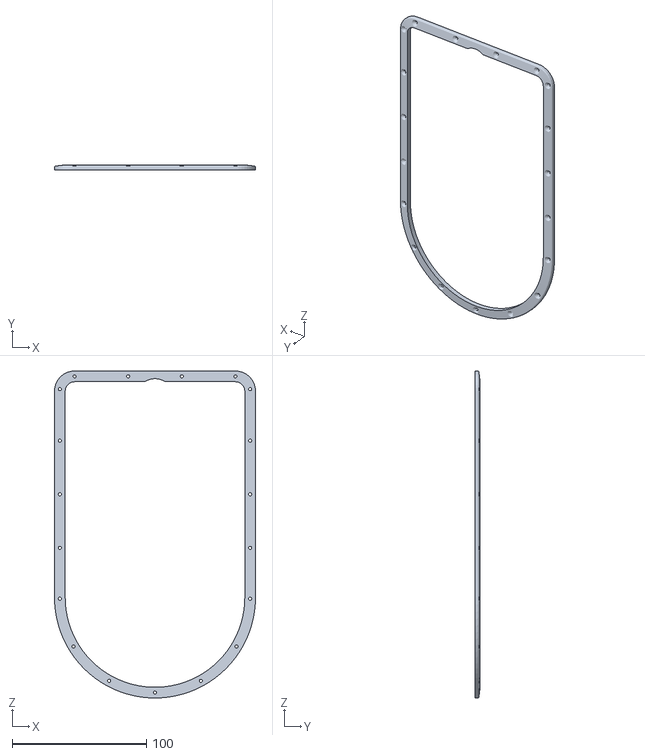
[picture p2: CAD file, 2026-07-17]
3d_designs/6-upper-skirt-mount-complete.stl
150.0 x 4.00 x 244.0

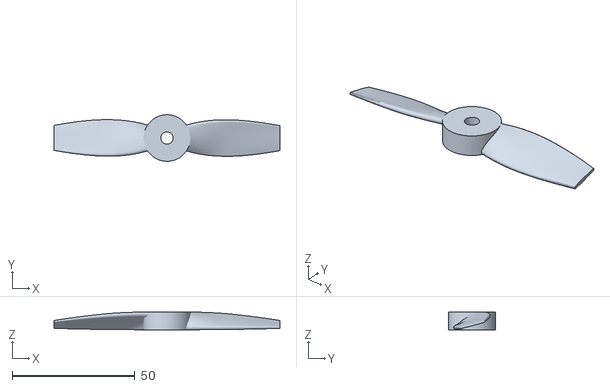
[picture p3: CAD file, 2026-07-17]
3d_designs/propeller.stl
92.0 x 19.0 x 7.29

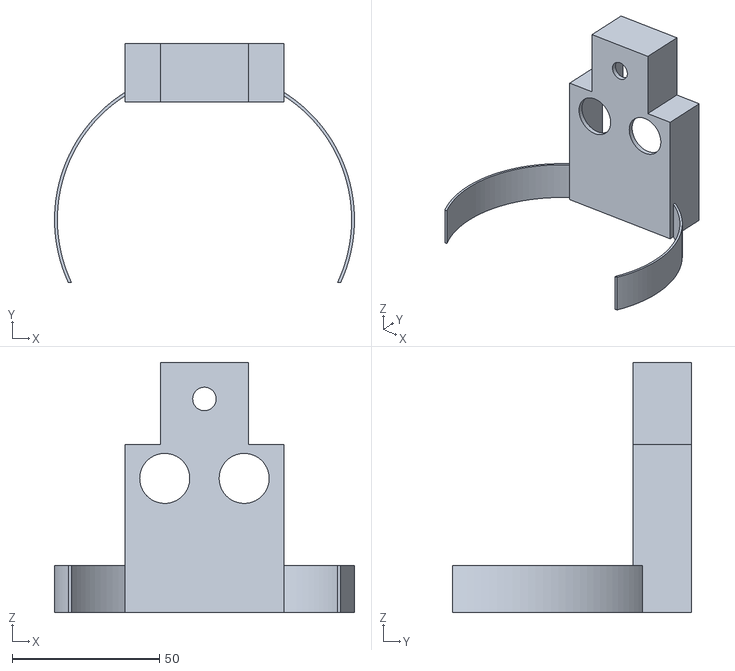
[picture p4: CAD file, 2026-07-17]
3d_designs/camerabox.stl
102.0 x 81.3 x 85.1

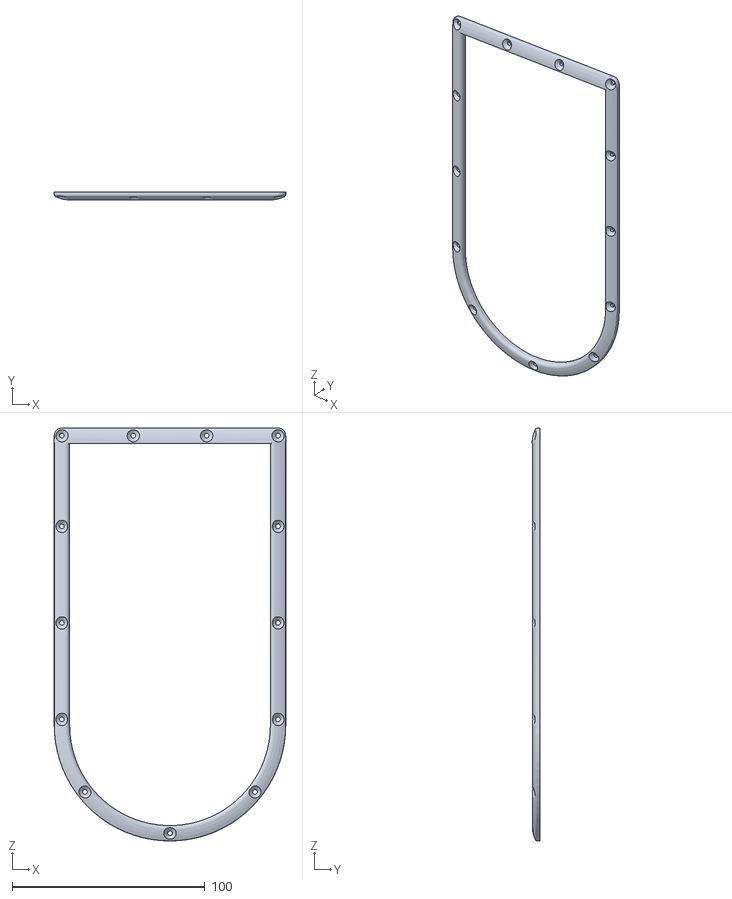
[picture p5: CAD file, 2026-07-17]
3d_designs/5-lower-skirt-mount.stl
120.0 x 4.00 x 214.0

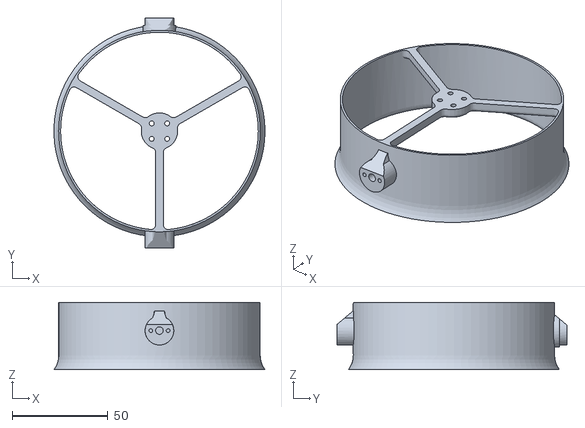
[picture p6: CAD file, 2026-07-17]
3d_designs/3-thrust-motor-mount.stl
110.0 x 120.0 x 35.0

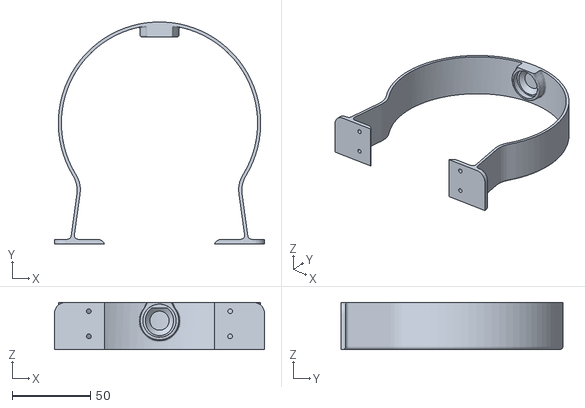
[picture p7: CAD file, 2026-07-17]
3d_designs/4-roll-hoop.stl
133.8 x 141.5 x 30.0

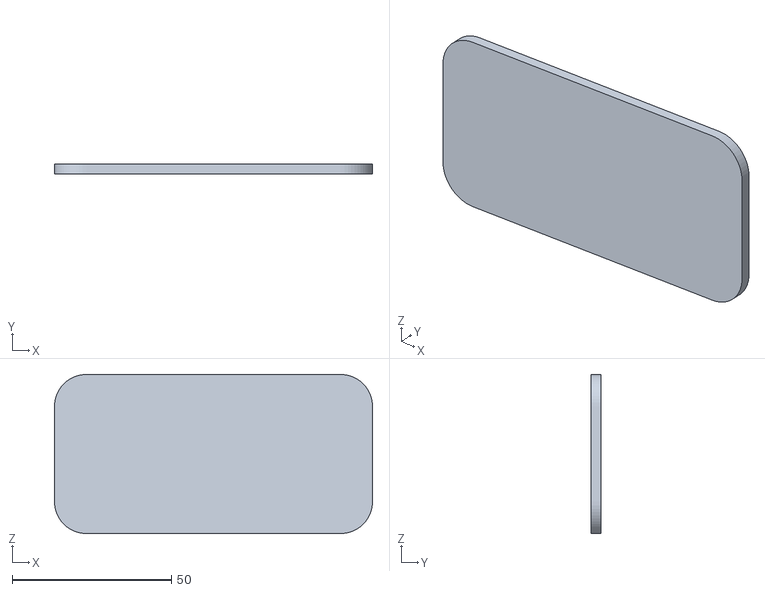
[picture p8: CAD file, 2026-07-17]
3d_designs/joycover.stl
100.0 x 3.00 x 50.0

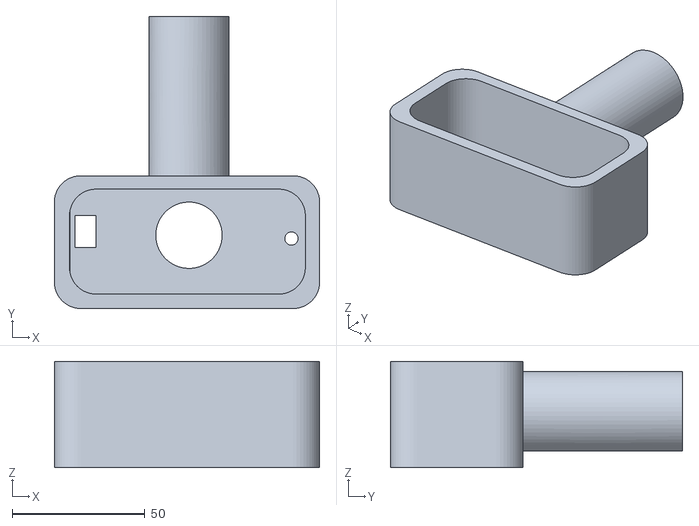
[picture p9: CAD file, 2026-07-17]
3d_designs/joystick.stl
100.0 x 110.0 x 40.0

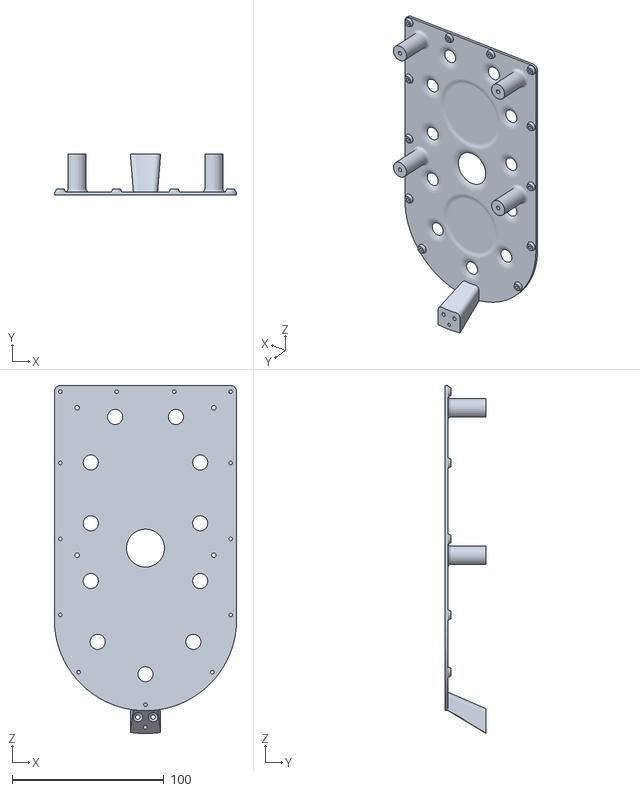
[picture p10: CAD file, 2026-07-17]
3d_designs/2-lower-hull.stl
120.0 x 27.0 x 229.0

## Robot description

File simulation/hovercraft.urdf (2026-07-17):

<?xml version="1.0" ?>
<robot name="hovercraft" xmlns:xacro="http://www.ros.org/wiki/xacro">

  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
  <link name="base_link">
    <inertial>
      <mass value="0.4"/>
      <origin xyz="0 0 0.02" rpy="0 0 0"/>
      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
    </inertial>

    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
  </link>

  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
  <link name="skirt_link">
    <inertial>
      <mass value="0.01"/>
      <origin xyz="0 0 -0.005" rpy="0 0 0"/>
      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
    </inertial>
    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
  </link>

  <joint name="skirt_joint" type="fixed">
    <parent link="base_link"/>
    <child link="skirt_link"/>
    <origin xyz="0 0 0" rpy="0 0 0"/>
  </joint>

  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
  <link name="thrust_mount">
    <inertial>
      <mass value="0.03"/>
      <origin xyz="-0.03 0 0.035" rpy="0 0 0"/>
      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
    </inertial>

    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
  </link>

  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
  <joint name="servo_joint" type="revolute">
    <parent link="base_link"/>
    <child link="thrust_mount"/>
    <origin xyz="-0.08 0 0.02" rpy="0 0 0"/>
    <axis xyz="0 0 1"/>
    <limit lower="0" upper="3.14159" effort="1.5" velocity="6.28"/>
    <dynamics damping="0.01" friction="0.005"/>
  </joint>

  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
  <link name="propeller_link">
    <inertial>
      <mass value="0.005"/>
      <origin xyz="0 0 0" rpy="0 0 0"/>
      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
    </inertial>

    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
  </link>

  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
  <joint name="prop_joint" type="continuous">
    <parent link="thrust_mount"/>
    <child link="propeller_link"/>
    <origin xyz="-0.03 0 0.06" rpy="0 0 0"/>
    <axis xyz="1 0 0"/>
    <dynamics damping="0.0001"/>
  </joint>

  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
  <link name="camera_link">
    <inertial>
      <mass value="0.01"/>
      <origin xyz="0 0 0" rpy="0 0 0"/>
      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
    </inertial>

    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
  </link>

  <joint name="camera_joint" type="fixed">
    <parent link="base_link"/>
    <child link="camera_link"/>
    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
    <origin xyz="0.10 0 0.035" rpy="0 0 0"/>
  </joint>

  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
  <link name="imu_link">
    <inertial>
      <mass value="0.002"/>
      <origin xyz="0 0 0" rpy="0 0 0"/>
      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
    </inertial>
  </link>

  <joint name="imu_joint" type="fixed">
    <parent link="base_link"/>
    <child link="imu_link"/>
    <origin xyz="0 0 0.02" rpy="0 0 0"/>
  </joint>

  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

</robot>

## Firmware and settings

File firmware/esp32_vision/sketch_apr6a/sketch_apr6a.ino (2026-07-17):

/*
 * sketch_apr6a.ino — ESP32-CAM Data Streamer (v5.4)
 * ====================================================
 * Platform  : ESP32-CAM (AI-Thinker)
 * Role      : Camera frame grab → person bounding-box geometry
 *             + HC-SR04 ultrasonic distance → 4-byte UART packet
 *
 * UART Protocol to Pico (115200 baud, 4 bytes):
 * ──────────────────────────────────────────────
 *   BYTE 0 : 0xD4         — sync header (geometry packet)
 *   BYTE 1 : aspect_x10   — uint8: bounding-box aspect ratio × 10
 *   BYTE 2 : bb_height    — uint8: bounding-box pixel height (0–255)
 *   BYTE 3 : ultra_dist   — uint8: ultrasonic distance in cm (0–255)
 *
 *   No CRC in this 4-byte compact format — sync header + field
 *   range validation on the Pico side provides adequate integrity.
 *
 * Ultrasonic Sensor (HC-SR04):
 *   TRIG_PIN = 13
 *   ECHO_PIN = 15
 *   Non-blocking timer: triggers pulse every 60 ms (well above the
 *   38 ms max echo timeout). Distance clamped to 255 cm on timeout.
 *
 * Camera:
 *   FRAMESIZE_QVGA (320×240) at ~10 FPS.
 *   Uses fb→buf for raw frame data.  Bounding-box detection is a
 *   placeholder — replace with your actual detection model or
 *   colour-blob / motion-delta logic.
 *
 * Pin Map (ESP32-CAM AI-Thinker):
 *   GPIO 13 → HC-SR04 TRIG
 *   GPIO 15 → HC-SR04 ECHO
 *   GPIO 1  → Serial TX (to Pico UART0 RX on GP1)
 *   GPIO 3  → Serial RX (unused by Pico)
 *
 * ⚠  GPIO 13 and 15 are shared with the SD card on AI-Thinker.
 *    SD card must NOT be initialised when using ultrasonic.
 */

#include "esp_camera.h"

// ── Ultrasonic Pins ──────────────────────────────────────────────────
#define TRIG_PIN  13
#define ECHO_PIN  15

// ── Non-blocking ultrasonic timing ───────────────────────────────────
//  State machine:
//    IDLE       → wait for interval timer
//    TRIGGERED  → 10µs pulse sent, waiting for echo
//
//  ULTRA_INTERVAL_MS must be > 38 ms (max echo round-trip for 6.5 m)
//  60 ms gives ~16 Hz measurement rate with zero camera interference.

#define ULTRA_INTERVAL_MS   60     // ms between trigger pulses
#define ULTRA_TIMEOUT_US    23200  // µs — max echo for ~400 cm (practical limit)

enum UltraState { ULTRA_IDLE, ULTRA_TRIGGERED };
static UltraState  ultra_state       = ULTRA_IDLE;
static uint32_t    ultra_last_ms     = 0;   // millis() of last trigger
static uint8_t     ultra_dist_cm     = 255; // last valid distance (255 = no echo)

// ── Camera pin definitions (AI-Thinker ESP32-CAM) ────────────────────
#define PWDN_GPIO_NUM     32
#define RESET_GPIO_NUM    -1
#define XCLK_GPIO_NUM      0
#define SIOD_GPIO_NUM     26
#define SIOC_GPIO_NUM     27
#define Y9_GPIO_NUM       35
#define Y8_GPIO_NUM       34
#define Y7_GPIO_NUM       39
#define Y6_GPIO_NUM       36
#define Y5_GPIO_NUM       21
#define Y4_GPIO_NUM       19
#define Y3_GPIO_NUM       18
#define Y2_GPIO_NUM        5
#define VSYNC_GPIO_NUM    25
#define HREF_GPIO_NUM     23
#define PCLK_GPIO_NUM     22

// ── Bounding-box state (from detection) ──────────────────────────────
static uint8_t  bb_aspect_x10 = 0;   // aspect ratio × 10 (0 = no detection)
static uint8_t  bb_height     = 0;   // pixel height (0 = no detection)

// ── Forward declarations ─────────────────────────────────────────────
void     ultra_tick();
void     send_geometry_packet();
void     detect_person(camera_fb_t *fb);
bool     init_camera();


// =====================================================================
//  SETUP
// =====================================================================

void setup() {
    Serial.begin(115200);   // UART to Pico (GP1 RX)

    // ── Ultrasonic GPIO ──────────────────────────────────────────────
    pinMode(TRIG_PIN, OUTPUT);
    pinMode(ECHO_PIN, INPUT);
    digitalWrite(TRIG_PIN, LOW);

    // ── Camera init ──────────────────────────────────────────────────
    if (!init_camera()) {
        Serial.println("[ESP32] Camera init FAILED");
        // Continue anyway — ultrasonic still works
    } else {
        Serial.println("[ESP32] Camera ready — QVGA 10 FPS");
    }

    Serial.println("[ESP32] v5.4 — Geometry + Ultrasonic streamer online");
    ultra_last_ms = millis();
}


// =====================================================================
//  MAIN LOOP — ~10 FPS camera + non-blocking ultrasonic
// =====================================================================

void loop() {
    // ── Non-blocking ultrasonic measurement ──────────────────────────
    ultra_tick();

    // ── Camera frame grab + detection ────────────────────────────────
    camera_fb_t *fb = esp_camera_fb_get();
    if (fb) {
        detect_person(fb);
        esp_camera_fb_return(fb);
    }

    // ── Send 4-byte geometry packet ──────────────────────────────────
    send_geometry_packet();
}


// =====================================================================
//  NON-BLOCKING ULTRASONIC
// =====================================================================
//
//  Called every loop() iteration.  Uses a timer to avoid blocking
//  the camera pipeline.  The pulseIn() call has a timeout so it
//  never hangs longer than ULTRA_TIMEOUT_US (~23 ms).
//
//  Measurement cadence: every ULTRA_INTERVAL_MS (60 ms).
//  Between measurements the function returns immediately (< 1 µs).

void ultra_tick() {
    uint32_t now = millis();

    if (ultra_state == ULTRA_IDLE) {
        // ── Wait for interval ────────────────────────────────────────
        if ((now - ultra_last_ms) < ULTRA_INTERVAL_MS) return;

        // ── Send 10 µs trigger pulse ─────────────────────────────────
        digitalWrite(TRIG_PIN, HIGH);
        delayMicroseconds(10);
        digitalWrite(TRIG_PIN, LOW);

        ultra_state   = ULTRA_TRIGGERED;
        ultra_last_ms = now;
    }

    if (ultra_state == ULTRA_TRIGGERED) {
        // ── Read echo (with timeout) ─────────────────────────────────
        //  pulseIn returns 0 on timeout.
        unsigned long duration_us = pulseIn(ECHO_PIN, HIGH, ULTRA_TIMEOUT_US);

        if (duration_us == 0) {
            // No echo — out of range or sensor error
            ultra_dist_cm = 255;
        } else {
            // Speed of sound ≈ 343 m/s → 29.15 µs/cm (round trip ÷ 2)
            unsigned long dist = duration_us / 58;   // cm
            ultra_dist_cm = (dist > 255) ? 255 : (uint8_t)dist;
        }

        ultra_state = ULTRA_IDLE;
    }
}


// =====================================================================
//  CAMERA INIT (AI-Thinker pinout)
// =====================================================================

bool init_camera() {
    camera_config_t config;
    config.ledc_channel = LEDC_CHANNEL_0;
    config.ledc_timer   = LEDC_TIMER_0;
    config.pin_d0       = Y2_GPIO_NUM;
    config.pin_d1       = Y3_GPIO_NUM;
    config.pin_d2       = Y4_GPIO_NUM;
    config.pin_d3       = Y5_GPIO_NUM;
    config.pin_d4       = Y6_GPIO_NUM;
    config.pin_d5       = Y7_GPIO_NUM;
    config.pin_d6       = Y8_GPIO_NUM;
    config.pin_d7       = Y9_GPIO_NUM;
    config.pin_xclk     = XCLK_GPIO_NUM;
    config.pin_pclk     = PCLK_GPIO_NUM;
    config.pin_vsync    = VSYNC_GPIO_NUM;
    config.pin_href     = HREF_GPIO_NUM;
    config.pin_sccb_sda = SIOD_GPIO_NUM;
    config.pin_sccb_scl = SIOC_GPIO_NUM;
    config.pin_pwdn     = PWDN_GPIO_NUM;
    config.pin_reset    = RESET_GPIO_NUM;
    config.xclk_freq_hz = 20000000;
    config.pixel_format = PIXFORMAT_JPEG;
    config.frame_size   = FRAMESIZE_QVGA;   // 320×240
    config.jpeg_quality = 12;
    config.fb_count     = 1;

    esp_err_t err = esp_camera_init(&config);
    return (err == ESP_OK);
}


// =====================================================================
//  PERSON DETECTION (placeholder — replace with your model)
// =====================================================================
//
//  This is a stub detection function.  Replace the body with your
//  actual detection pipeline (TFLite Micro, colour-blob, motion-delta,
//  or any ML model running on the ESP32).
//
//  The function must set:
//    bb_aspect_x10  — bounding-box width/height × 10 (uint8, 0–255)
//    bb_height      — bounding-box pixel height      (uint8, 0–255)
//
//  Set both to 0 when no detection is present.

void detect_person(camera_fb_t *fb) {
    // ── PLACEHOLDER: no detection by default ─────────────────────────
    // Replace this section with your actual detection code.
    //
    // Example (if you have a bounding box from a model):
    //   float aspect = (float)bb_w / (float)bb_h;
    //   bb_aspect_x10 = constrain((uint8_t)(aspect * 10.0f), 0, 255);
    //   bb_height     = constrain(bb_h, 0, 255);
    //
    // For now: output zeros (no human detected)
    bb_aspect_x10 = 0;
    bb_height     = 0;
}


// =====================================================================
//  SEND 4-BYTE GEOMETRY PACKET
// =====================================================================
//
//  Packet format:
//    [0xD4] [aspect_x10] [bb_height] [ultra_dist_cm]
//
//  Sent once per loop() call (~10 Hz, paced by camera frame rate).
//  No CRC — the Pico validates via sync byte + field range checks.

void send_geometry_packet() {
    uint8_t packet[4];
    packet[0] = 0xD4;            // Sync header
    packet[1] = bb_aspect_x10;   // Aspect ratio × 10
    packet[2] = bb_height;       // Bounding-box pixel height
    packet[3] = ultra_dist_cm;   // Ultrasonic distance (0–255 cm)

    Serial.write(packet, 4);
}

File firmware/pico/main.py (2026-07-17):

"""
main.py — Dual-Core Entry Point (1700KV 4-Layer 3cm Skirt v5.4)
================================================================
Raspberry Pi Pico (RP2040) — MicroPython

Core 0 : ESP32-Cam UART0 obstacle veto (ABSOLUTE PRIORITY)
         + 0xD4 Geometry Packet parser (Aspect/Height/UltraDist)
         + Arduino Nano UART1 serial packet parser
Core 1 : MPU-6050 IMU → calibrate → MLP tilt-rudder → PWM @ 100 Hz

Changes in v5.4 vs v5.3
------------------------
1. 0xD4 Geometry Packet expanded to 4 bytes (was 5-byte CRC format):
   [0xD4][aspect_x10][bb_height][ultra_dist_cm]
   Ultrasonic distance from ESP32-CAM HC-SR04 sensor.

2. Dual-Veto Braking:
   STATE_BRAKING triggers on human AI confirmation (latched)
   OR ultrasonic proximity < 25 cm (proximity stop, auto-clears).

3. [V5.4] Telemetry with DIST field for ultrasonic verification.

Previous features (v3.8–v5.3) unchanged:
  Angle Integration (Heading Memory), Pilot Overrule,
  Post-Inflation Lock-In, Max-Input Thrust Mixer,
  Snap burst, auto-idle thermal relief, MLP tilt-rudder PI,
  obstacle veto, failsafe, LPF, confidence gate, post-inflate cal.

Pin Map
-------
  GP0  → UART0 TX  (reserved)
  GP1  ← UART0 RX  (ESP32-Cam TX → obstacle veto + geometry)
  GP4  ↔ MPU-6050 SDA (I2C0)
  GP5  ↔ MPU-6050 SCL (I2C0)
  GP8  → UART1 TX  (reserved)
  GP9  ← UART1 RX  (Nano via 1 kΩ/2 kΩ divider)
  GP16 → Lift ESC PWM
  GP17 → Thrust ESC PWM
  GP18 → Servo PWM

Nano Serial Protocol (9600 8N1)
--------------------------------
  [0xAA][0x55][thrust][steer][lift][ai][brake][crc]
  CRC = thrust ^ (steer & 0xFF) ^ lift ^ ai ^ brake
"""

import _thread
import time
import struct
from machine import Pin, I2C, UART

import hover_control
import mlp_logic
import weights

# ── Configuration ─────────────────────────────────────────────────────
AI_GAIN        = 1.0    # locked for 3 cm heavy-skirt stability testing
CONTROL_HZ     = 100
CONTROL_TICK   = 10     # ms
# GYRO_DEADZONE is now defined in hover_control.py (0.08 °/s) ← v5.5
# Used here via hover_control.GYRO_DEADZONE for consistent jitter filtering.

# =====================================================================
#  SHARED STATE
# =====================================================================

_lock = _thread.allocate_lock()

_shared = {
    "joy_x":        0.0,
    "joy_y":        0.0,
    "lift_on":      False,
    "ai_mode":      False,
    "brake_mode":   False,
    "obstacle_dir": 0,
    "last_rx_ms":   0,
    "do_inflate":   False,
    "cam_aspect":   0.0,      # v4.2: ESP32 0xD4 geometry — aspect ratio
    "cam_height":   0,        # v4.2: ESP32 0xD4 geometry — pixel height
    "ultra_dist":   255,      # v5.4: ultrasonic distance cm (255 = no echo)
}


def _shared_read():
    _lock.acquire()
    snap = dict(_shared)
    _lock.release()
    return snap


def _shared_write(**kwargs):
    _lock.acquire()
    for k, v in kwargs.items():
        _shared[k] = v
    _lock.release()


# =====================================================================
#  ESP32-CAM — UART0 (GP1 RX)
# =====================================================================
#
# Packet protocol (4 bytes, sent by ESP32-CAM):
#
#   [0xAB][DIR][DIST][CRC]
#
#   0xAB  — sync byte
#   DIR   — direction code:  0=clear  1=brake  2=left  3=right
#   DIST  — distance in cm, uint8 (0–254). 255 = no object detected.
#   CRC   — 0xAB ^ DIR ^ DIST  (1-byte XOR checksum)
#
# Obstacle threshold: OBSTACLE_TRIGGER_CM = 20
#   DIST > 20 or DIST == 255  →  clear (code 0).
#   DIST <= 20                →  DIR code forwarded to control loop.
#
# Legacy fallback: old single-byte ASCII '0'–'3' still decoded,
#   forwarded as direction-only with no distance filtering.
#
# ESP32-CAM Arduino sketch send function:
#   void send_obstacle(uint8_t dir, uint8_t dist_cm) {
#       uint8_t crc = 0xAB ^ dir ^ dist_cm;
#       Serial.write(0xAB);
#       Serial.write(dir);
#       Serial.write(dist_cm);
#       Serial.write(crc);
#   }
#   // Send dist_cm=255 when no object is detected.
#
# === 0xD4 Geometry Packet (v5.4 — 4-Byte Compact) ====================
#
#   [0xD4][aspect_x10][bb_height][ultra_dist_cm]
#
#   0xD4           — sync byte for geometry data
#   aspect_x10     — uint8: aspect ratio × 10 (e.g. 6 → 0.6)
#   bb_height      — uint8: bounding box pixel height (0–255)
#   ultra_dist_cm  — uint8: ultrasonic distance in cm (0–255)
#
#   No CRC — compact format.  Validated by sync byte + range.
#   Used by is_human_signature() in hover_control.py.
#   Ultrasonic distance stored in shared["ultra_dist"].
# =====================================================================

OBSTACLE_TRIGGER_CM = 20    # veto activates at this distance or closer

_cam_uart  = None
_cam_buf   = bytearray()
_CAM_SYNC  = 0xAB
_CAM_PKT   = 4              # bytes per new-format packet
_CAM_GEO_SYNC = 0xD4        # v5.4: geometry packet sync byte
_CAM_GEO_PKT  = 4           # v5.4: geometry packet length (4 bytes, no CRC)
_last_cam_dist = 255        # last reported distance (cm); 255 = no object


def _init_cam_uart():
    global _cam_uart
    _cam_uart = UART(0, baudrate=115200, tx=Pin(0), rx=Pin(1))
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

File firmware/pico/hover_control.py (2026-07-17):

"""
hover_control.py — PWM Management & Safety Logic (1700KV 2-Blade v5.4)
=======================================================================
Manages Lift BLDC (GP16), Thrust BLDC (GP17), and Servo (GP18).

All PWM values in microseconds (us).  50 Hz PWM → 20 000 us period.
ESC range: 1000 us (off) → 2000 us (full).
Servo:     500 us (0 deg) → 2500 us (180 deg).

Optimised for: Emax 1700KV | 4-Layer Garbage Bag Skirt (3 cm) | 12.6 V 3S 80C
               Reduced skirt height (3 cm vs previous) lowers the
               required hover RPM to 11 500 vs 12 531 in v3.6.
               Inflation burst shortened to 0.6 s ("Snap" burst)
               at 1700 µs — sufficient to pop the lighter 3 cm bag.

RPM / PWM reference  (1700KV × 12.6 V = 21 420 RPM at 100%)
--------------------------------------------------------------
  Formula:  RPM = ((us - 1000) / 1000) × 21 420
  1000 µs →      0 RPM  (armed, off)
  1300 µs →  6 426 RPM  ← _IDLE_LIFT_SCALE 0.85 × 1536 (ESC cooling)
  1536 µs → 11 484 RPM  ← PRIMARY HOVER TARGET (≈ 11 500 RPM) ← v3.8
  1700 µs → 14 994 RPM  ← SNAP BURST (0.6 s, 3 cm skirt pop)   ← v3.8
  1800 µs → 17 136 RPM  ← EMERGENCY / HARD CEILING (manual peak)← v3.8
  2000 µs → 21 420 RPM  (never reached)

⚠  IDLE SCALE NOTE
   _IDLE_LIFT_SCALE = 0.85 drops lift to 1305 µs / ~6 524 RPM
   (0.85 × 1536 = 1305.6 → rounded 1305 µs).
   At 12.6 V this remains above the sustain threshold for a 3 cm
   4-layer bag.  If skirt deflation is observed during the 5 s
   cooling window, raise to 0.95 (→ 1459 µs / ~9 809 RPM).

Changes in v5.4 vs v5.3
------------------------
1. Dual-Veto Braking:
   STATE_BRAKING triggered by human AI confirmation (latched, requires
   joystick reset) OR ultrasonic proximity < ULTRA_PROXIMITY_CM (25 cm,
   auto-clears when obstacle moves away).
2. ULTRA_PROXIMITY_CM constant added for ultrasonic proximity threshold.
3. All v5.3 features unchanged: Angle Integration, Pilot Overrule,
   Post-Inflation Lock-In, Max-Input Thrust Mixer.
"""

from machine import Pin, PWM
import time

# ── Constants ─────────────────────────────────────────────────────────

PWM_FREQ       = 50         # Hz — strictly 50 Hz (RC ESC standard, switching efficiency)
PWM_PERIOD_US  = 20_000
PWM_MIN        = 1000       # ESC arm / off
PWM_MAX        = 2000       # absolute max (never sent to lift in normal flight)
PWM_LIFT_CAP   = 1350       # RPM throttle cap — max lift output µs   ← v5.6
                             # 1350 µs ≈ 7 500 RPM.  Lift capped at
                             # hover RPM to prevent floating.

# ── Lift BLDC — 7 500 RPM (3 cm 4-layer skirt, sealed hull) ──────────
LIFT_MIN_PWM      = 1350    # 7 500 RPM — PRIMARY hover constant     ← v5.6
LIFT_HOVER_PWM    = 1350    # alias kept for compute_targets()        ← v5.6
LIFT_BURST_PWM    = 1350    # 7 500 RPM — same as hover              ← v5.6
                             # No burst spike — steady 7.5K RPM for
                             # inflation and flight.
LIFT_BURST_TICKS  = 30      # ticks @ 100 Hz = 0.3 s hold            ← v5.6
LIFT_INFLATE_PWM  = 1350    # settle target after burst               ← v5.6
LIFT_MAX_PWM      = 1350    # 7 500 RPM — hard ceiling                ← v5.6

# Soft-start ramp (burst → settle, driven non-blocking in Core 1)
LIFT_RAMP_STEP_US = 10      # µs per tick during settle ramp          ← v5.5
                             # Raised from 5 — settles to 13K RPM faster
                             # (1650→1607 = 4.3 ticks ≈ 43 ms)
LIFT_RAMP_TICK_MS = 10      # ms reference (= CONTROL_TICK)

# Deadband — 25 µs suppresses ESC jitter at 11 500 RPM
# Jitter at this RPM inside a sealed hull is the primary MOSFET heat source.
LIFT_DEADBAND_US  = 25      # µs  (was 30 in v3.6)                   ← v3.8

# Thrust BLDC
THRUST_IDLE_PWM   = 1100
THRUST_MAX_PWM    = 1900

# Thrust-dip manoeuvre
THRUST_DIP_PWM    = 1100
THRUST_DIP_MS     = 100

# Voltage-sag ramp rate
RAMP_STEP         = 50      # max µs change per 10 ms tick

# Servo (MG90S)
SERVO_MIN         = 500
SERVO_NEUTRAL     = 1500
SERVO_MAX         = 2500

# ── v3.9 Steering compensation ────────────────────────────────────────
#
# FORWARD_MIX_TRIM
#   Corrects leftward yaw bias during forward thrust (joy_y > 0).
#   The thrust fan torque reacts against the skirt and pulls the nose
#   left.  This constant adds a fixed rightward servo offset to cancel
#   it.  Increase in steps of 5 µs until the craft tracks straight.
#   Typical range: +15 to +30 µs.  Start at +20.
FORWARD_MIX_TRIM  = 25     # µs rightward bias during forward flight ← v4.2 tuned
#
# TILT_RUDDER_GAIN
#   Scales how aggressively the MLP roll-tilt correction moves the
#   rudder servo.  Units: µs of servo deflection per g of roll.
#   At 1.0 g of roll (craft on its side), full TILT_RUDDER_GAIN is
#   applied.  Typical in-flight tilt ≈ ±0.1–0.3 g → ±20–60 µs trim.
#   Start at 200. Raise for snappier correction, lower if oscillating.
TILT_RUDDER_GAIN  = 280    # µs/g roll correction scale            ← v5.3 raised
#
# TILT_RUDDER_DEADBAND_G
#   Tilt corrections smaller than this (in g) are ignored entirely.
#   Prevents the servo from hunting/buffering around the zero point.
#   0.03 g ≈ 1.7° tilt — below this, treat as level.
TILT_RUDDER_DEADBAND_G = 0.10   # g — ignore tilt smaller than this ← v5.4 raised
                                # 0.03 was too sensitive at 13K RPM — motor vibration
                                # read as tilt, causing false thrust boost.
#
# TILT_RUDDER_LPF_ALPHA
#   Low-pass filter coefficient for the tilt-rudder signal.
#   Lower = smoother but slower response. Higher = faster but noisier.
#   0.15 gives ~65 ms lag at 100 Hz — smooth without being sluggish.
TILT_RUDDER_LPF_ALPHA  = 0.25   # LPF on tilt-rudder trim           ← v5.3 faster
#
# Yaw PI controller gains
# P gain: µs of rudder per g of tilt error. 150 = gentle correction.
# I gain: µs of rudder per g·tick of accumulated error.
#         At 100 Hz, 1 tick = 10 ms. 0.8 µs/(g·tick) accumulates
#         ~8 µs/s per 0.1g of persistent tilt — slow but persistent.
# I limit: caps the integrator at ±80 µs to prevent windup.
YAW_KP       = 200.0    # µs/g  proportional gain               ← v5.3 raised
YAW_KI       = 2.0      # µs/(g·tick) integral gain             ← v5.3 raised
YAW_KI_LIMIT = 100.0    # µs  integrator clamp (anti-windup)    ← v5.3 raised
JOY_DEADZONE       = 0.05      # joystick deadzone for manual inputs  ← v5.5
                                # Inputs within ±0.05 are forced to 0
                                # to prevent jitter in yaw_trim.
GYRO_DEADZONE      = 5.0       # IMU gyro deadzone (°/s)              ← v5.5
                                # Aggressively filters motor vibration
                                # (1–5°/s).  Only real spins (>5°/s)
                                # pass through.  Applied to spin_err_dps.
#
# LIFT_SOFTSTART_STEP_US
#   µs added to lift PWM per tick during soft-start ramp.
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

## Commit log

2026-07-17 Initial commit: Autonomous AI Hovercraft v5.5
    - Raspberry Pi Pico (RP2040) dual-core flight controller
    - TinyML MLP 7→8→4 inference at 100 Hz (mlp_logic.py, weights.py)
    - hover_control.py: PWM, heading memory, thrust-dip, safety (v5.6)
    - main.py: dual-core, ESP32-Cam veto, Nano RX bridge parser (v5.4)
    - transmitter_nano.ino: 433 MHz TX, 6-byte packet, connection feedback
    - receiver_nano.ino: 433 MHz RX → UART bridge to Pico (NEW)
    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
    [hovercraft.urdf]
2026-07-17 Add ball bearing 6702 to components list
2026-07-17 Reorganize project structure
    - All firmware moved into firmware/ folder:
    firmware/pico/ → main.py, hover_control.py, mlp_logic.py, weights.py
    firmware/transmitter_nano/ → transmitter_nano.ino
    firmware/receiver_nano/ → receiver_nano.ino
    firmware/esp32_vision/ → sketch_apr6a.ino
    - 3D design STL files added in 3d_designs/ (10 parts: hull, mounts, enclosures)
    - README updated: new folder tree, corrected flash paths, 3D section
    - README: expanded self-correction / heading-hold feature description
    [1-upper-hull-main-body.stl, 2-lower-hull.stl, 3-thrust-motor-mount.stl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]
